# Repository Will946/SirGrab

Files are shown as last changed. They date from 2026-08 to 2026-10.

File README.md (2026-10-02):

# Robotic Arm Project

A 3D-printed robotic arm, driven by an Arduino Uno R3 and a PCA9685 PWM
servo board, controlled through a live 3D interface in the browser.

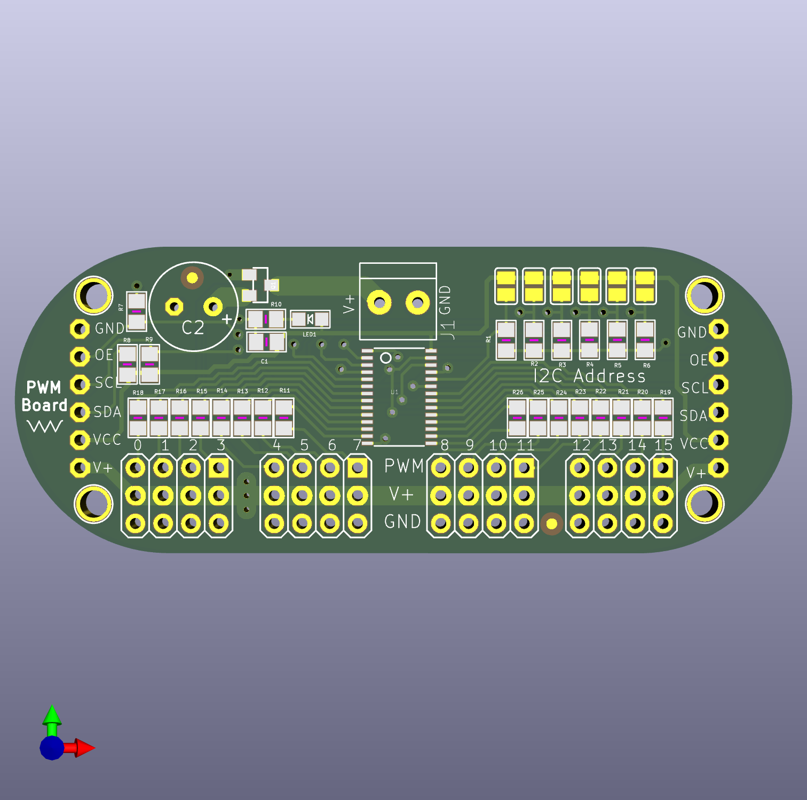
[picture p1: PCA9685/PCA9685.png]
PCA9685 PWM driver board


The PCA9685 is a 16-channel PWM driver board built around Adafruit's
Arduino-based PWM servo driver design, controlled here by an Arduino Uno
R3. The Arduino doesn't drive the servos directly. It talks to the
PCA9685 over I2C, and the board generates all 16 PWM signals on its own.
This is what lets a single Arduino control far more servos than its own
pins could handle directly, without fighting timer conflicts.

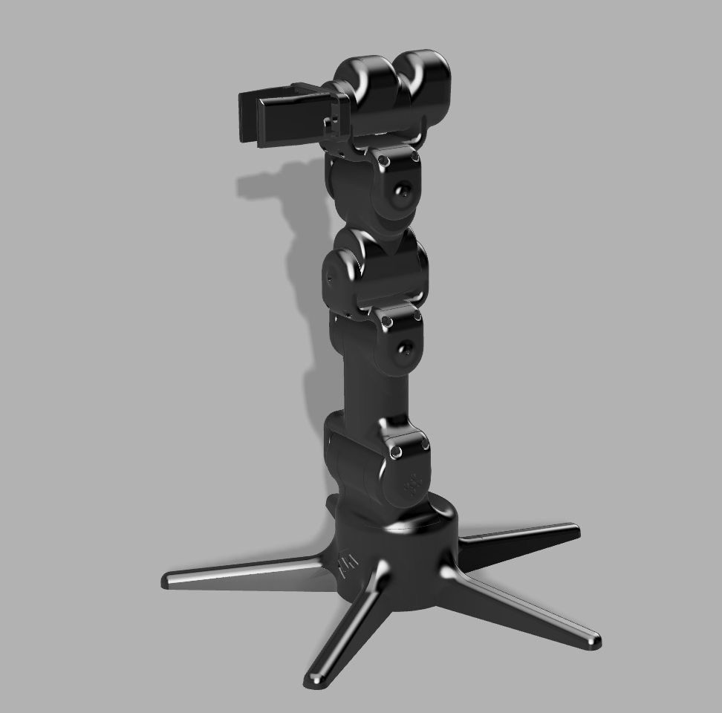
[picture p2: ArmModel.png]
Arm model


The arm itself is 3D printed in PETG, using roughly 900g of filament for
the full model.

## Channel map and calibration

| Ch | Joint | Motion | Calibration center |
|----|---|---|---|
| 0  | Base | Rotates parallel to the ground | 90, no fixed reference direction |
| 3 / 8 | Bottom hinge | Up/down, mirrored pair | 75 / 105 |
| 12 | 3rd hinge | Up/down | 90 |
| 7  | 2nd hinge | Bends left/right, perpendicular plane to the other hinges | 105 |
| 4  | Topmost hinge | Up/down | 90 |
| 15 | Grip rotation | Twists around the claw's own pointing axis | 60 |
| 11 | Grip | Open/close | 90, no fixed reference direction |

Ch3 and ch8 are mechanically mirrored, since they physically face each
other. Their raw angles always sum to 180. Both the Arduino sketch and
the control script derive one from the other so they can never drift
apart from rounding.

## How it works

`arm_final_control.ino` listens over serial for `channel:angle` commands
and applies each one immediately, with no internal ramping. Early on, the
sketch did ramp motion on its own, stepping one degree at a time with a
delay between steps. That caused a real bug: with the control side also
trying to smooth motion, the Arduino would be mid-delay and stop reading
incoming serial data, the buffer backed up, and the arm would freeze or
desync. Moving all smoothing to the control side and keeping the Arduino
a simple instant-write listener fixed it. The control side owns pacing,
the Arduino just executes, and that split is the architecture everything
downstream is built on.

The control side is a two-part local setup. A small Python bridge script
opens the actual serial connection to the Arduino and a local WebSocket
server. A browser page renders the arm in 3D using three.js and exposes a
slider per joint. Each joint rotates on its real physical axis. Up/down
hinges bend in one plane, the 2nd hinge bends in the perpendicular plane,
and the grip rotation twists around the claw's own pointing direction,
like a screwdriver bit, rather than around the arm's main axis.

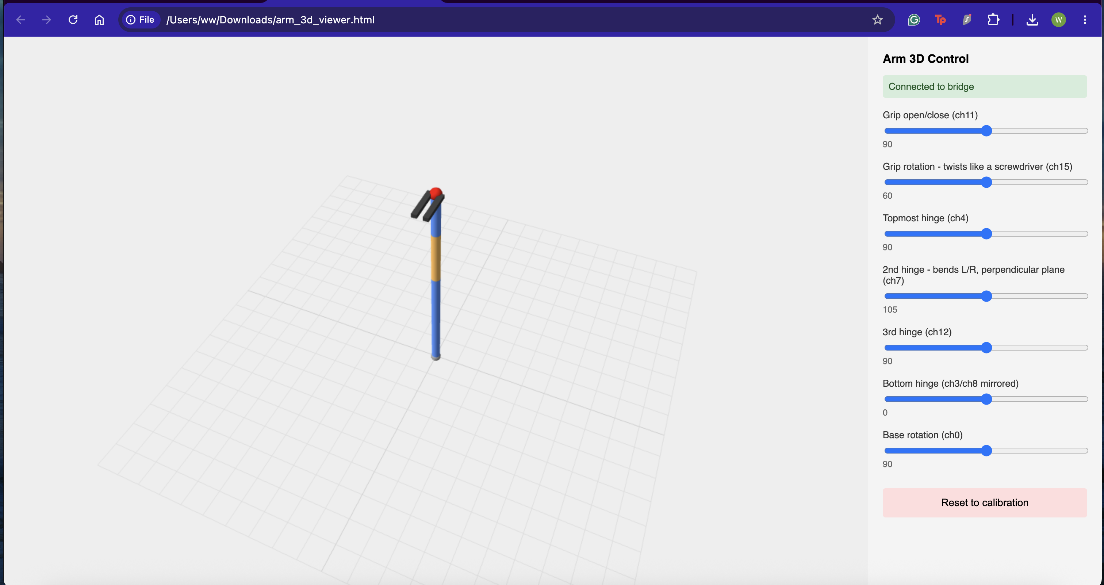
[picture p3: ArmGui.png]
Arm 3D Control interface


Dragging a slider doesn't jump the arm straight to the new position.
Every joint has a target, wherever the slider currently is, and a current
value, what's actually been sent so far. A smoothing loop nudges the
current value a small step closer to the target roughly 50 times a
second. That's what keeps motion gradual, both from the browser
interaction and from any script that talks to the bridge.

Each slider's range is centered on that joint's own calibration value
instead of just running 0 to 180 for everything, and is capped to a
safety window. That means it's not possible to drag a joint into a
position closer to its mechanical limit than intended.

There's a second control page, `arm_gamepad_control.html`, that connects
to the same bridge and drives the arm with a PS5 DualSense controller
instead of sliders. The left stick handles base rotation and the bottom
hinge, the right stick handles the 2nd and 3rd hinge, the triggers handle
the topmost hinge, the bumpers handle grip rotation, and the face buttons
open and close the grip. This is velocity control, not position control.
Holding a stick or trigger moves the joint at a constant rate for as long
as it's held, rather than mapping stick position directly to arm
position. Every joint still respects the same calibrated safety range as
the sliders, so holding an input at the edge of its range just holds the
joint there instead of continuing to push against the limit.

## Limitations of the current approach

- **Control is entirely manual.** Posing the arm means dragging sliders
  one at a time. There's no way to move several joints together with one
  gesture, and definitely no way to "reach for" a position the way a real
  arm would.
- **No feedback loop.** The system has no idea where the arm actually is
  beyond what it last commanded. If a servo stalls, gets physically
  blocked, or the arm is bumped, nothing detects or corrects for it.
- **No inverse kinematics.** Every joint is set independently by angle.
  There's no way to say "move the gripper to this point in space" and
  have the joints figure out how to get there together.
- **Slider control doesn't scale well to fast or complex motion.** It's
  fine for careful positioning, but clumsy for anything that needs to
  happen quickly across multiple joints at once.

## Limitations of gamepad control

- **Stick drift.** Analog sticks often don't rest at exactly zero on
  every axis, and that resting bias can be enough to register as
  unintended input on its own. The gamepad page has a calibration button
  that measures each axis's true resting position and uses that as zero
  instead of assuming it's perfectly centered.
- **Cross-talk during a push, which calibration can't fix.** Calibration
  only measures the stick at rest. Pushing a stick in a straight line
  along one axis can still leak a small signal into the other axis on
  some hardware, this showed up as pushing straight down also triggering
  a small rotation. The fix in place compares both axes on a stick each
  frame and suppresses the smaller one whenever one axis is clearly
  dominant, so single-axis pushes read as single-axis input. Genuine
  diagonal pushes, where both axes are deliberately similar in magnitude,
  still pass through normally.
- **Calibration doesn't persist.** Stick calibration resets every time
  the page is reloaded and has to be redone each session.
- **Button and axis index mapping can vary between controllers and
  browsers.** The standard layout assumed here, for example buttons 6 and
  7 for the triggers, is common but not guaranteed. A different
  controller or browser may need the index numbers adjusted.
- **The Gamepad API only recognizes a controller per browser tab, and
  only after a real button press while that tab is focused.** Pairing a
  controller over Bluetooth, or detecting it on another page, doesn't
  carry over automatically. Each new tab needs its own button press to
  register the controller.

## Currently working on

Exploring computer-vision-based control so the arm can mirror real arm
movement directly, rather than being posed joint by joint through
sliders. Two directions being evaluated: Google's MediaPipe pose and hand
tracking, and a marker-based tracking approach using printed fiducial
tags on the arm itself. Either would replace manual slider control with
live tracking of an actual human arm's position.

Both approaches run into the same core issue: a single camera struggles
to reliably measure rotation around certain axes. Bending a joint up and
down, toward or away from the camera, is easy to see. Twisting a joint,
like forearm rotation or wrist twist, is much harder, since a monocular
camera has no real depth information and the visual cue for "this segment
just rotated along its own length" is subtle. Certain angles are
genuinely difficult to achieve reliably this way, particularly when a
tracked segment is edge-on to the camera or briefly occluded by another
part of the arm or hand. Marker-based tracking helps with the flexion and
extension angles, but rotation still needs either a better camera angle,
multiple markers per segment to catch whichever one is currently facing
the camera, or a fallback like an IMU for the axes vision alone can't
resolve well.

## Development environment

This was built and run on macOS. Every Python script here expects to run
inside a virtual environment rather than the system Python, both to keep
dependencies isolated and because macOS's built-in Python has caused
real problems in this project, including a broken Tk installation that
crashed the GUI outright until a separate Python install was used
instead. Setup looks like this:

```bash
python3 -m venv arm_env
source arm_env/bin/activate
pip install pyserial opencv-contrib-python numpy websockets
```

The virtual environment needs to be activated in any new terminal window
before running a script. Only one program can hold the Arduino's serial
port open at a time, so the Arduino IDE's Serial Monitor has to be closed
before running anything here.

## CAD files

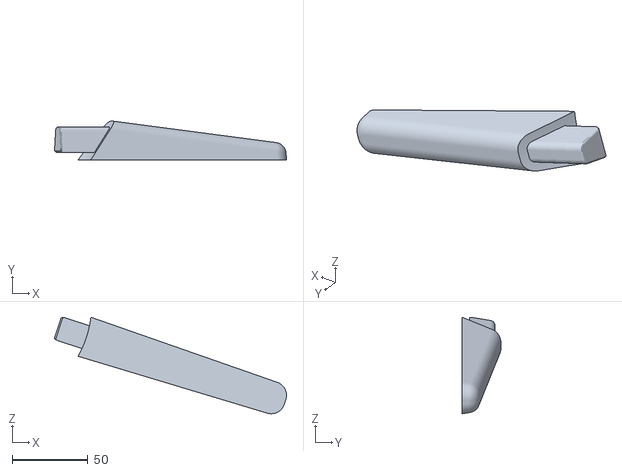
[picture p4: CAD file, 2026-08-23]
Basestl/Support_Leg_2.stl
153.3 x 25.6 x 63.8

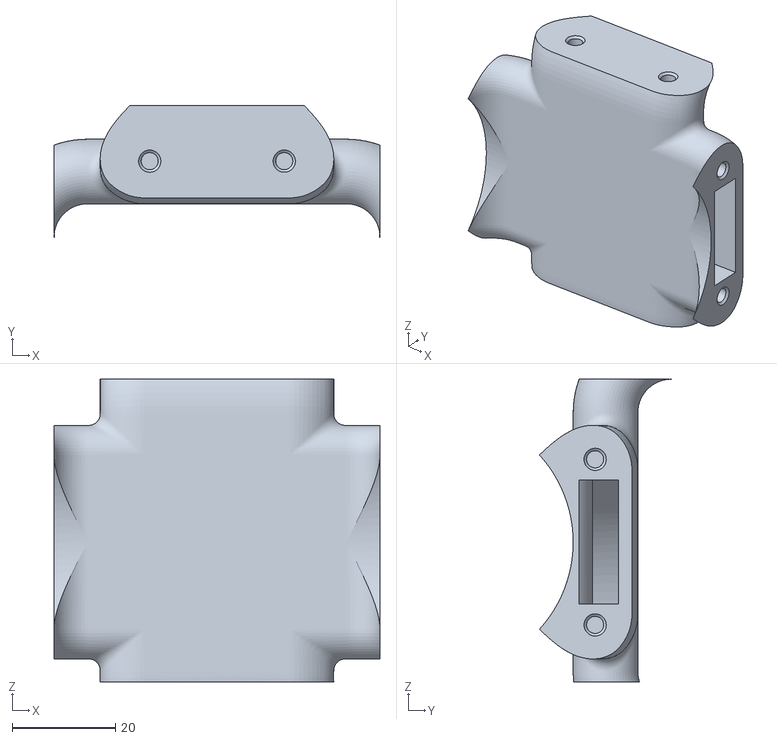
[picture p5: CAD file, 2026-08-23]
GripperHeadstl/Gripper_joint_connector.stl
63.0 x 25.5 x 58.5

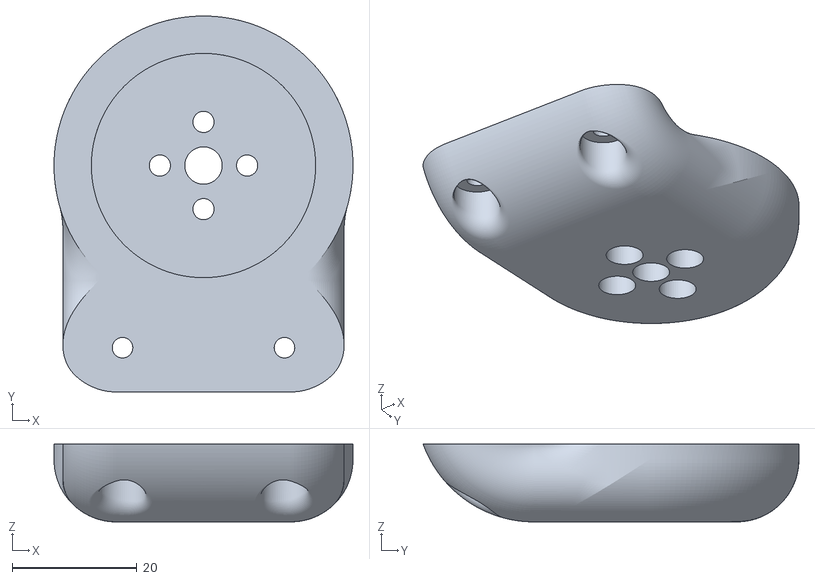
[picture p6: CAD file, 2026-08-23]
MainArmstl/Forearm–Arm_joint_1.stl
48.0 x 60.4 x 12.5

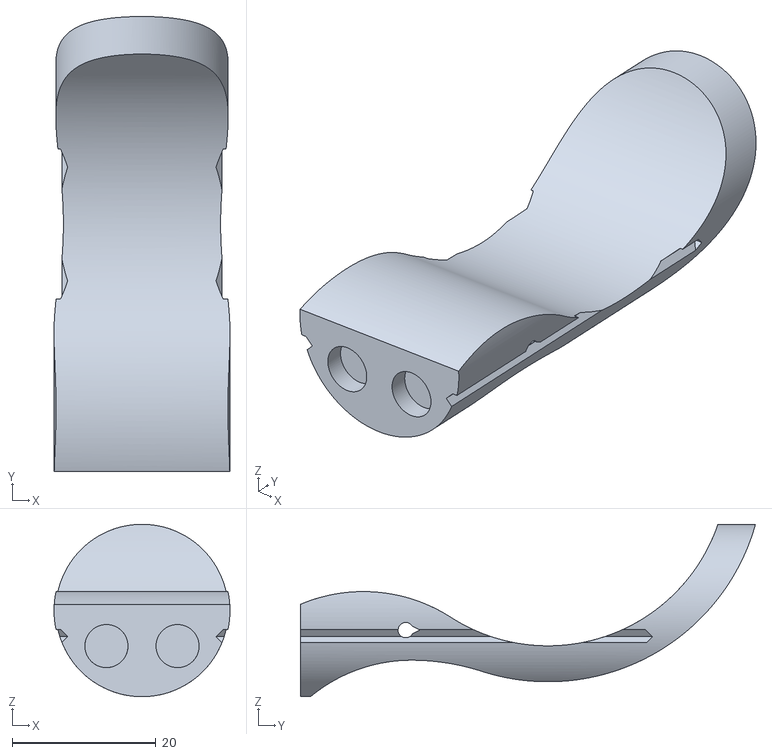
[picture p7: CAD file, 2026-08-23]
Basestl/Rotating_base_central_cover.stl
24.5 x 63.3 x 24.0

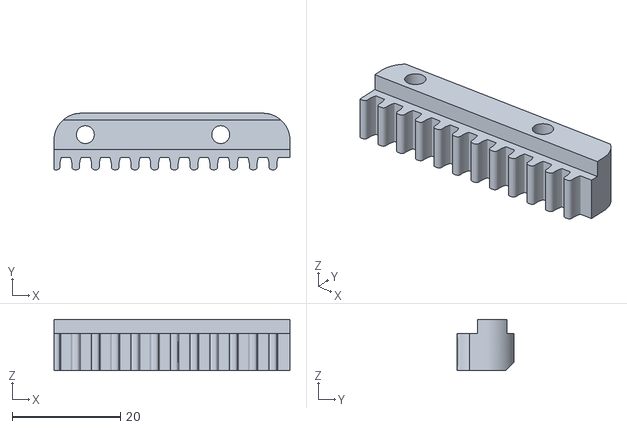
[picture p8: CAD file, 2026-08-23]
GripperHeadstl/Rack_gear_2.stl
43.6 x 10.4 x 9.50

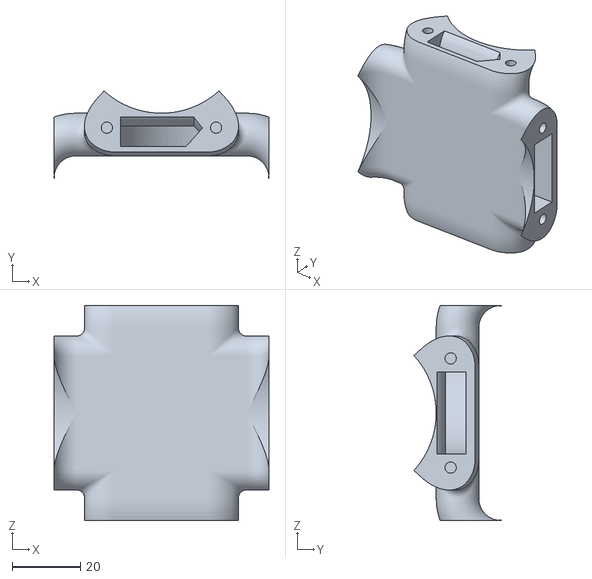
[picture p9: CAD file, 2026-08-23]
MainArmstl/Forearm–Arm_joint_5.stl
63.0 x 25.5 x 63.0

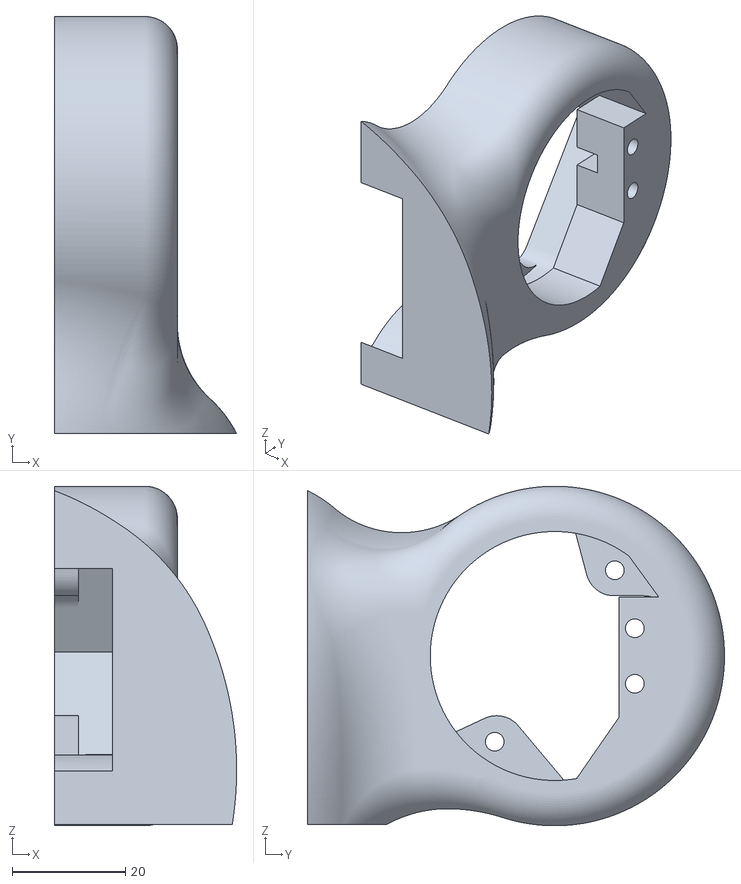
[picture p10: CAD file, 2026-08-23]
Basestl/Rotating_base_adapter_for_servo2.stl
32.2 x 73.7 x 60.0

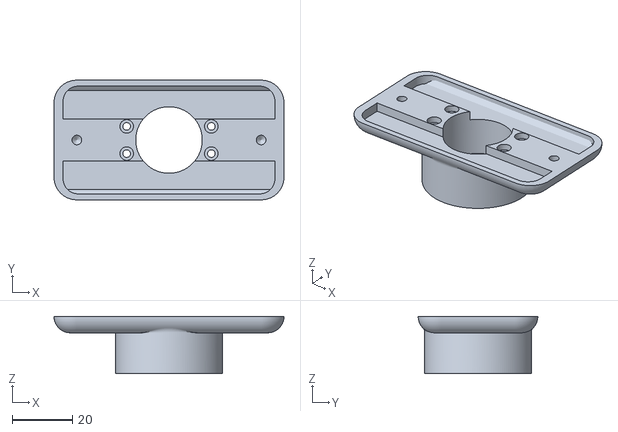
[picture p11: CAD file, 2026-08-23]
GripperHeadstl/Gripper_rack_and_shaft_housing.stl
76.1 x 39.6 x 18.9

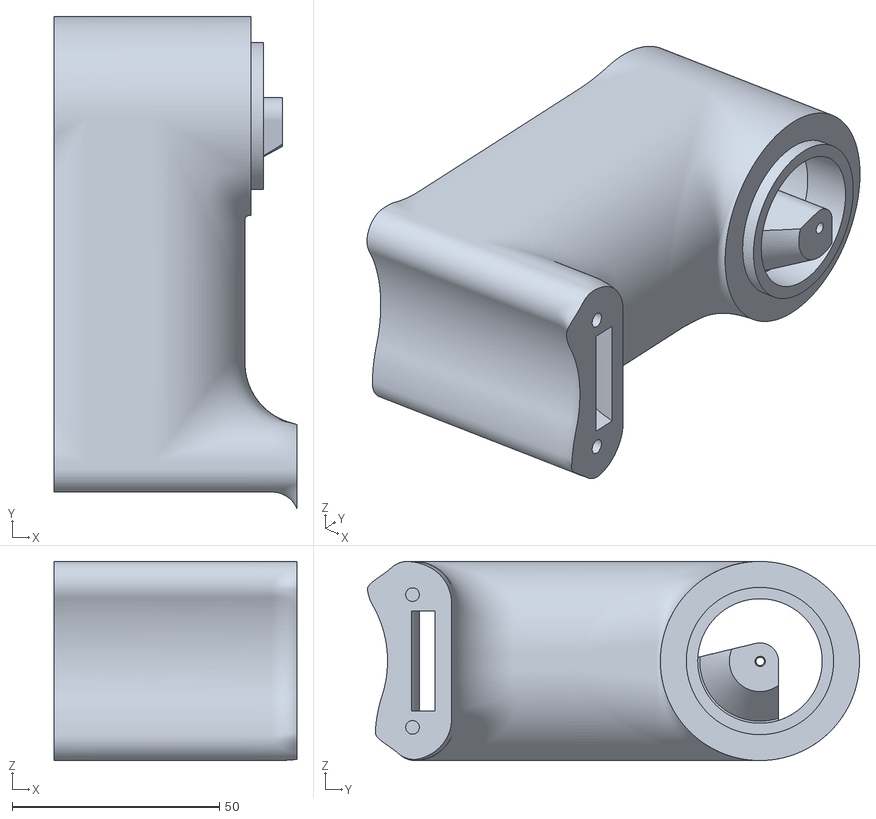
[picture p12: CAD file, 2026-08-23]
MainArmstl/Forearm_part_for_shaft.stl
58.5 x 118.6 x 48.0

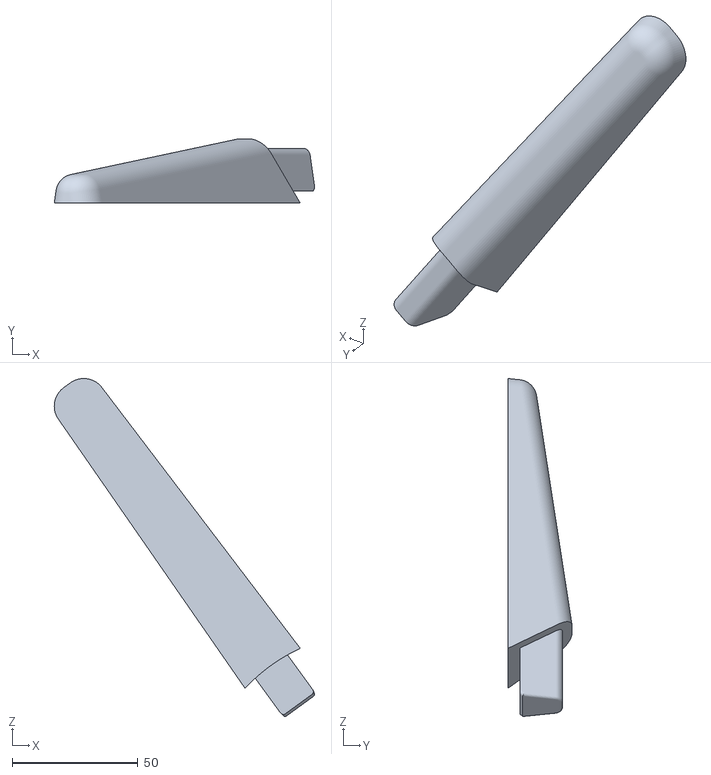
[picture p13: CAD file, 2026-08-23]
Basestl/Support_Leg_4.stl
103.8 x 25.6 x 134.7

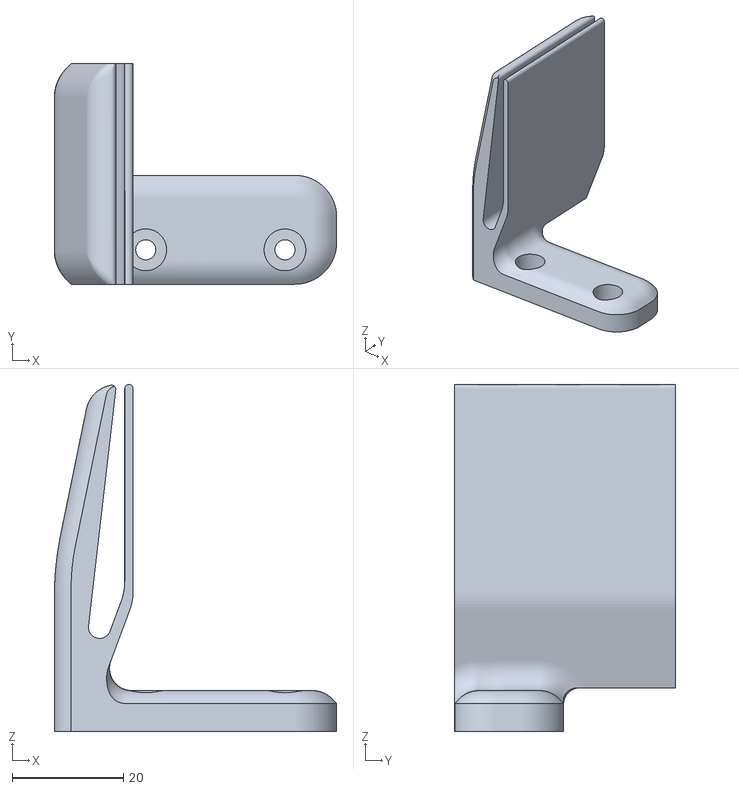
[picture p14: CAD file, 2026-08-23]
GripperHeadstl/Gripper_finger_1.stl
50.7 x 39.6 x 62.3

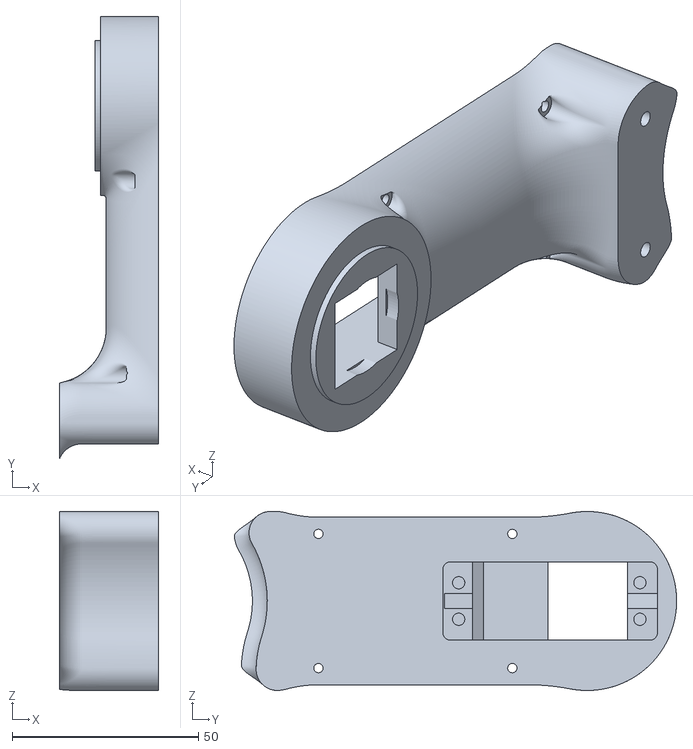
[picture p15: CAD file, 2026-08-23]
MainArmstl/Forearm_for_servo.stl
26.5 x 118.6 x 48.0

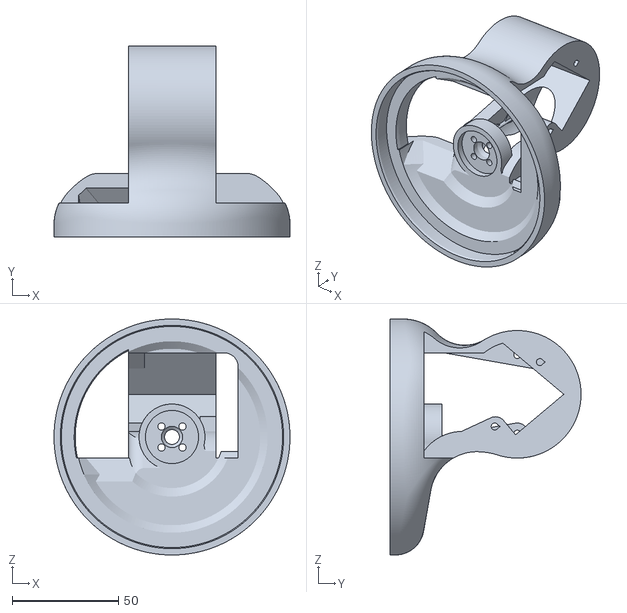
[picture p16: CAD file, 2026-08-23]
Basestl/Rotating_base.stl
111.0 x 89.9 x 111.0

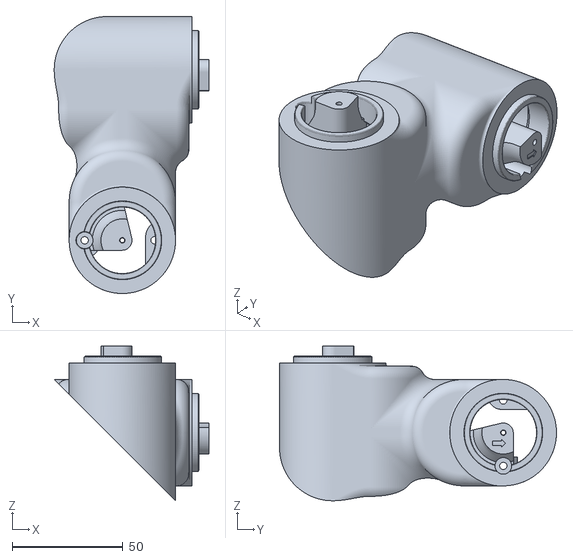
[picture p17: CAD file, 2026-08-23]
MainArmstl/Arm_part_for_shafts.stl
69.7 x 125.0 x 69.7

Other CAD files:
GripperHeadstl/Rack_gear_1.stl
Basestl/Fixed_base.stl
GripperHeadstl/Gripper_cover.stl
MainArmstl/Forearm–Arm_joint_2.stl
Basestl/Rotating_base_adapter_for_servo1.stl
Basestl/Support_Leg_1.stl
Basestl/Support_Leg_3.stl
Basestl/Support_Leg_5.stl
GripperHeadstl/Gripper_finger_2.stl
GripperHeadstl/Gripper_gear.stl
GripperHeadstl/Gripper_joint_(servo).stl
GripperHeadstl/Gripper_joint_(shaft).stl
GripperHeadstl/Gripper_servo_housing_(rotary_part).stl
GripperHeadstl/Gripper_shaft_support.stl
GripperHeadstl/Rack_gear_housing.stl
GripperHeadstl/Rotary_Body_of_the_Gripper.stl
GripperHeadstl/Servo_mount_for_gripper_rotation.stl
MainArmstl/Arm_part_for_servos.stl
MainArmstl/Forearm_rotation_joint_1.stl
MainArmstl/Forearm_rotation_joint_2.stl
MainArmstl/Forearm–Arm_joint_3.stl
MainArmstl/Forearm–Arm_joint_4.stl

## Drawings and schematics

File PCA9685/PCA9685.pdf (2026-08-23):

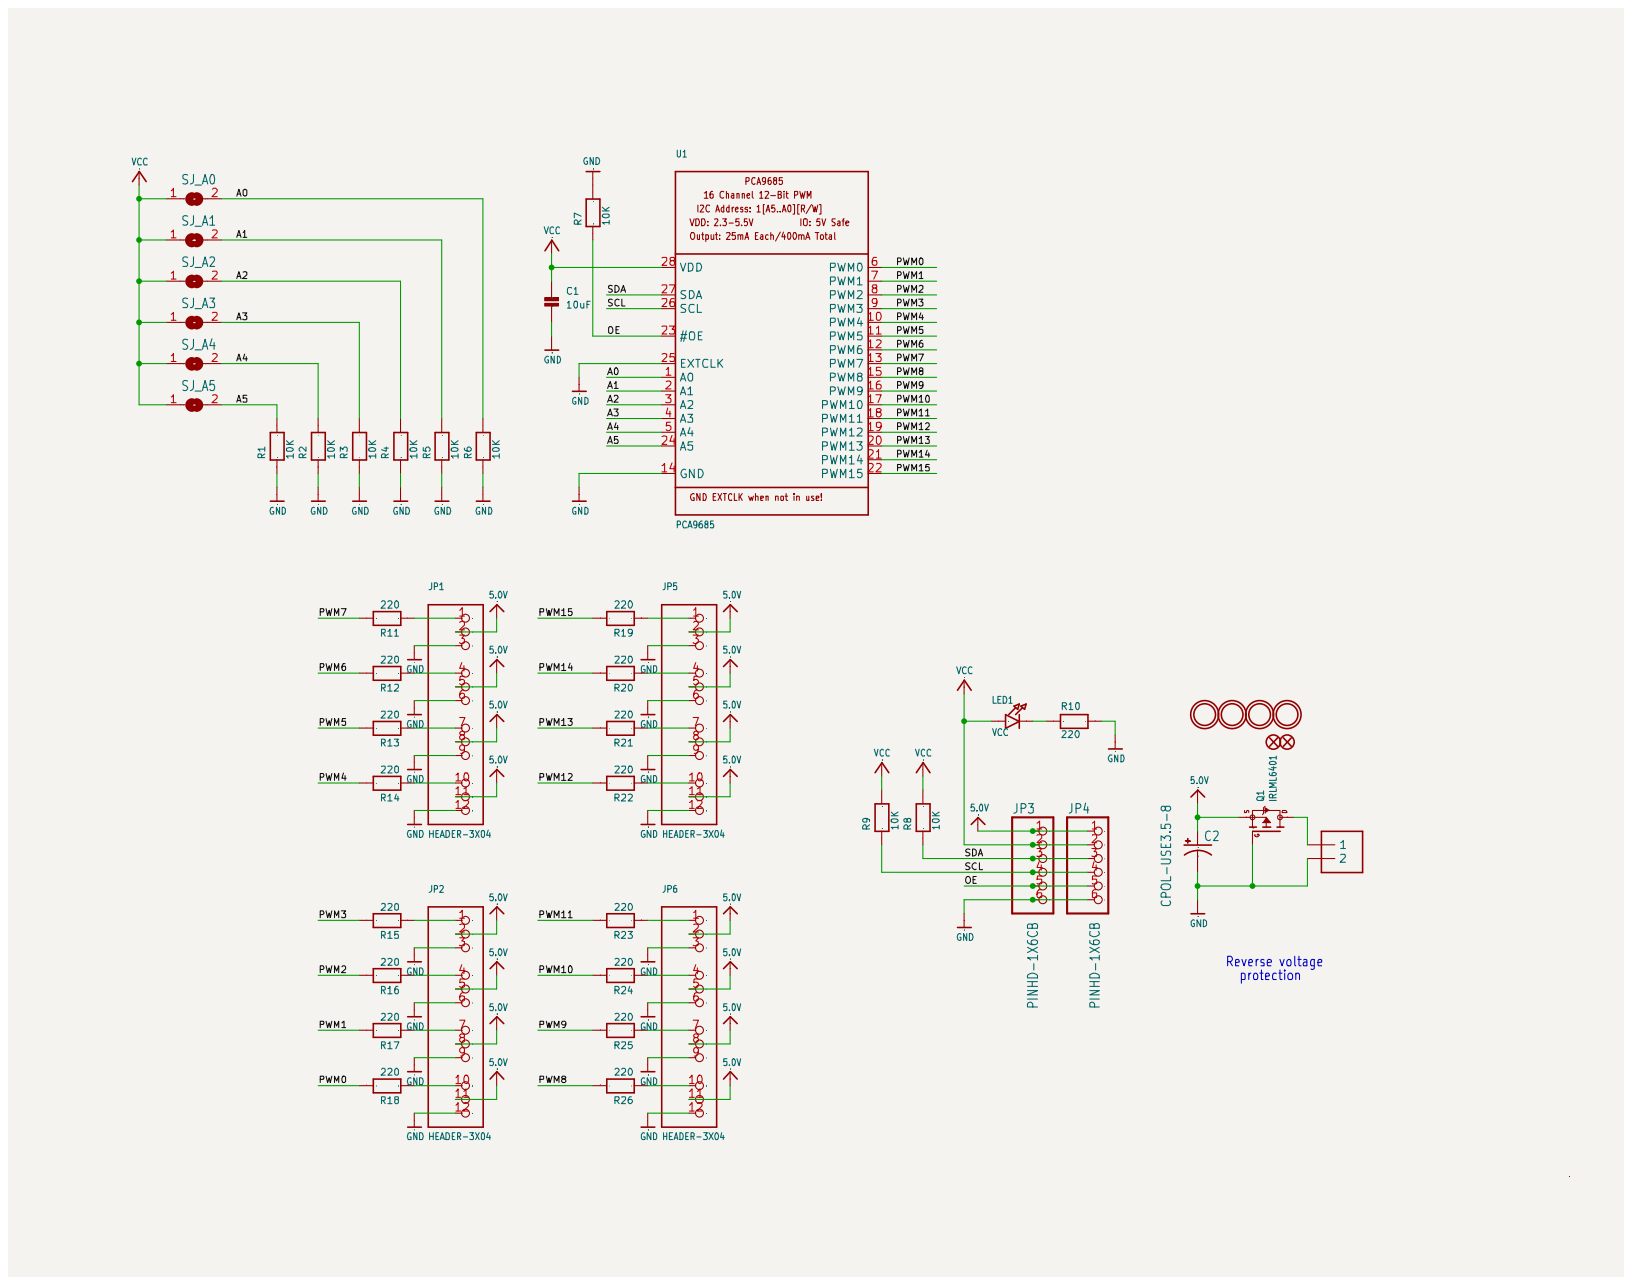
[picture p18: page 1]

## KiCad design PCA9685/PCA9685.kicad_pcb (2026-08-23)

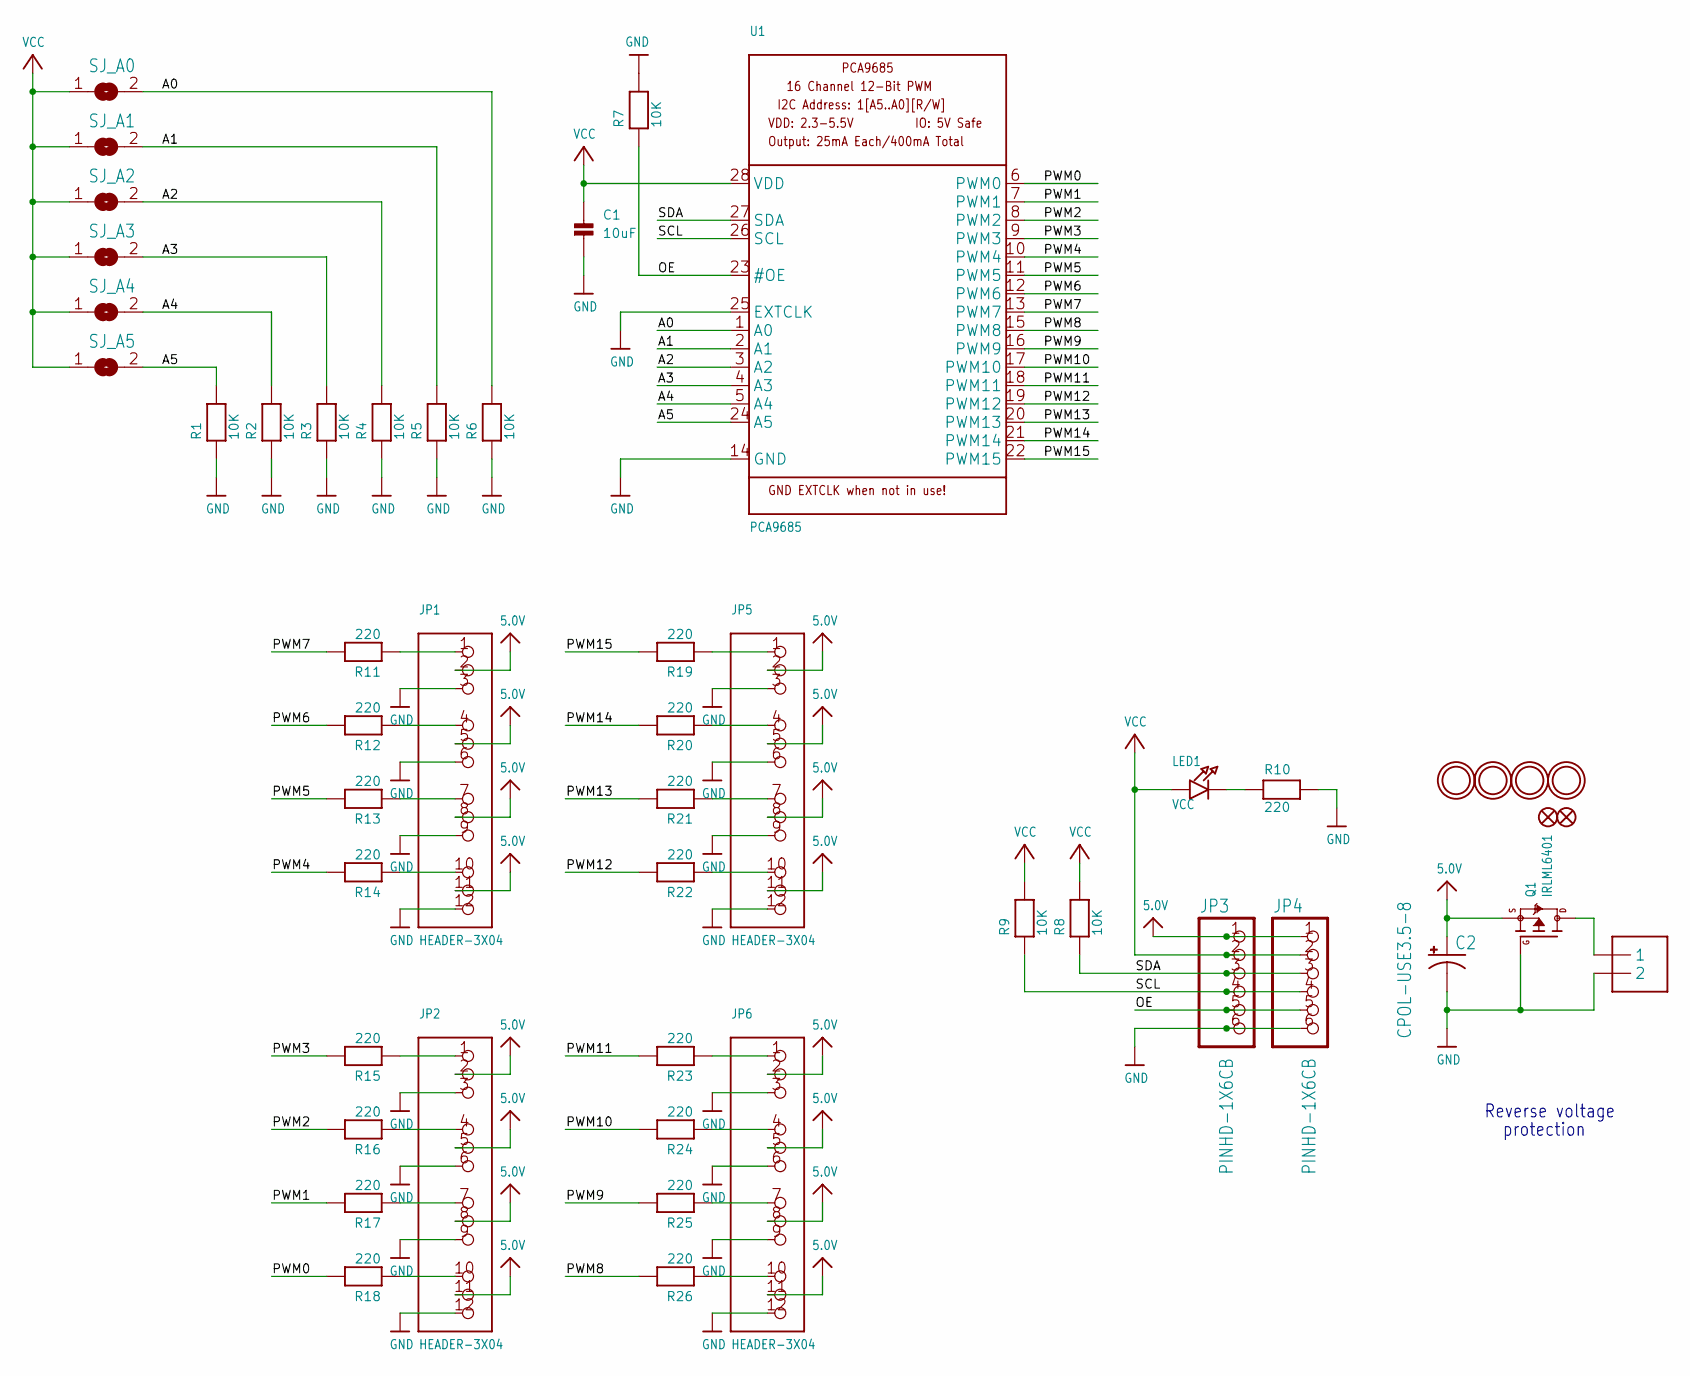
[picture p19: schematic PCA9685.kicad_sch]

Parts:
C1: 10uF; 0805
C2: CPOL-USE3.5-8; E3,5-8
FID1, FID2: FIDUCIAL""; FIDUCIAL_1MM
J1: TERMBLOCK_1X2-3.5MM; 1X2-3.5MM
JP1, JP2, JP5, JP6: HEADER-3X04; 3X04
JP3, JP4: PINHD-1X6CB; 1X06-CLEANBIG
LED1: VCC; CHIPLED_0805
Q1: IRLML6401; SOT23-WIDE
R1, R2, R3, R4, R5, R6, R7, R8, R9: 10K; 0805
R10, R11, R12, R13, R14, R15, R16, R17, R18, R19, R20, R21, R22, R23, R24, R25, R26: 220; 0805
SJ_A0, SJ_A1, SJ_A2, SJ_A3, SJ_A4, SJ_A5: SOLDERJUMPERREFLOW_NOPASTE; SOLDERJUMPER_REFLOW_NOPASTE
U1: PCA9685; TSSOP28
U$47, U$48, U$49, U$50: MOUNTINGHOLE2.5; MOUNTINGHOLE_2.5_PLATED

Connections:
5.0V: C2.+, JP1.2, JP1.5, JP1.8, JP1.11, JP2.2, JP2.5, JP2.8, JP2.11, JP3.1, JP4.1, JP5.2, JP5.5, JP5.8, JP5.11, JP6.2, JP6.5, JP6.8, JP6.11, Q1.2 (S)
A0: R6.2, SJ_A0.2, U1.1 (A0)
A1: R5.2, SJ_A1.2, U1.2 (A1)
A2: R4.2, SJ_A2.2, U1.3 (A2)
A3: R3.2, SJ_A3.2, U1.4 (A3)
A4: R2.2, SJ_A4.2, U1.5 (A4)
A5: R1.2, SJ_A5.2, U1.24 (A5)
GND: C1.2, C2.-, J1.2, JP1.3, JP1.6, JP1.9, JP1.12, JP2.3, JP2.6, JP2.9, JP2.12, JP3.6, JP4.6, JP5.3, JP5.6, JP5.9, JP5.12, JP6.3, JP6.6, JP6.9, JP6.12, Q1.1 (G), R1.1, R2.1, R3.1, R4.1, R5.1, R6.1, R7.2, R10.2, U1.14 (GND), U1.25 (EXTCLK)
unnamed: LED1.C, R10.1
unnamed: JP1.4, R12.1
unnamed: JP1.1, R11.1
unnamed: JP1.7, R13.1
unnamed: JP1.10, R14.1
unnamed: JP2.1, R15.1
unnamed: JP2.4, R16.1
unnamed: JP2.7, R17.1
unnamed: JP2.10, R18.1
unnamed: JP6.10, R26.1
unnamed: JP6.7, R25.1
unnamed: JP6.4, R24.1
unnamed: JP6.1, R23.1
unnamed: JP5.10, R22.1
unnamed: JP5.7, R21.1
unnamed: JP5.4, R20.1
unnamed: JP5.1, R19.1
OE: JP3.5, JP4.5, R7.1, U1.23 (#OE)
PWM0: R18.2, U1.6 (PWM0)
PWM1: R17.2, U1.7 (PWM1)
PWM2: R16.2, U1.8 (PWM2)
PWM3: R15.2, U1.9 (PWM3)
PWM4: R14.2, U1.10 (PWM4)
PWM5: R13.2, U1.11 (PWM5)
PWM6: R12.2, U1.12 (PWM6)
PWM7: R11.2, U1.13 (PWM7)
PWM8: R26.2, U1.15 (PWM8)
PWM9: R25.2, U1.16 (PWM9)
PWM10: R24.2, U1.17 (PWM10)
PWM11: R23.2, U1.18 (PWM11)
PWM12: R22.2, U1.19 (PWM12)
PWM13: R21.2, U1.20 (PWM13)
PWM14: R20.2, U1.21 (PWM14)
PWM15: R19.2, U1.22 (PWM15)
PWRIN: J1.1, Q1.3 (D)
SCL: JP3.4, JP4.4, R9.1, U1.26 (SCL)
SDA: JP3.3, JP4.3, R8.1, U1.27 (SDA)
VCC: C1.1, JP3.2, JP4.2, LED1.A, R8.2, R9.2, SJ_A0.1, SJ_A1.1, SJ_A2.1, SJ_A3.1, SJ_A4.1, SJ_A5.1, U1.28 (VDD)

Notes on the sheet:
Reverse voltage
protection

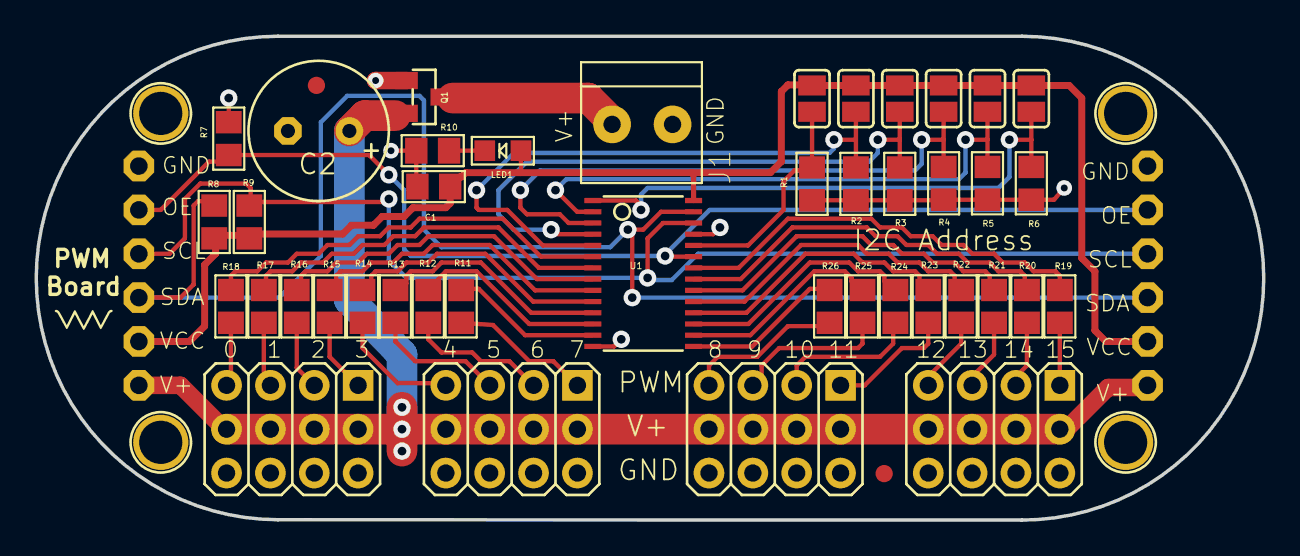
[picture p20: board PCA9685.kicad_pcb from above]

Board: 2 copper layers, 71.1 x 28.0 mm, 50 parts (0 on the bottom side), 46 nets.

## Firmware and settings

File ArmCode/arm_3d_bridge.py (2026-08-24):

"""
Local serial bridge for the 3D arm viewer.

The 3D view runs in your browser and can't talk to the Arduino directly
(browsers can't open serial ports on their own). This script is the piece
that actually holds the serial connection - it runs locally, opens a
WebSocket server, and forwards whatever angles the browser sends over to
the Arduino.

Install deps first (inside your venv):
    pip install pyserial websockets

Run this FIRST, then open arm_3d_viewer.html in your browser:
    python arm_3d_bridge.py
"""

import asyncio
import websockets
import serial
import json
import time

SERIAL_PORT = "/dev/tty.usbmodemE8F60AA9A0342"  # <-- update if your port differs
BAUD_RATE = 115200
WS_PORT = 8765

CALIBRATION = {
    0: 90, 3: 75, 8: 105, 4: 90, 7: 105, 11: 90, 12: 90, 15: 60,
}

try:
    ser = serial.Serial(SERIAL_PORT, BAUD_RATE, timeout=1)
    time.sleep(2)
    print("Connected to Arduino.")
except Exception as e:
    ser = None
    print(f"No serial connection ({e}) - bridge will run but won't move anything.")

last_sent = {}


def send_command(channel, angle):
    angle = int(max(0, min(180, angle)))
    if last_sent.get(channel) == angle:
        return
    last_sent[channel] = angle
    if ser:
        ser.write(f"{channel}:{angle}\n".encode())
    print(f"Ch{channel} -> {angle}")


async def handle_client(websocket):
    print("Browser connected.")

    # Send the whole arm to calibration once a browser tab connects
    for ch, angle in CALIBRATION.items():
        send_command(ch, angle)

    try:
        async for message in websocket:
            data = json.loads(message)
            channel = data.get("channel")
            angle = data.get("angle")
            if channel is not None and angle is not None:
                send_command(channel, angle)
    except websockets.exceptions.ConnectionClosed:
        print("Browser disconnected.")


async def main():
    async with websockets.serve(handle_client, "localhost", WS_PORT):
        print(f"Bridge running on ws://localhost:{WS_PORT}")
        print("Now open arm_3d_viewer.html in your browser.")
        await asyncio.Future()  # run forever


if __name__ == "__main__":
    asyncio.run(main())
